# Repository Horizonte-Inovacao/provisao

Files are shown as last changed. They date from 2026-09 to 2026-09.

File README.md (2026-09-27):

<p align="center">
  <!-- [MÍDIA] Substituir pelo logo oficial (versão horizontal, Petróleo + Coral) exportado do manual de marca -->
  <em>(espaço reservado para o logo da Horizonte Inovação Assistiva)</em>
</p>

# PróVisão

**Transformando o desafio em solução.** Um boné que avisa, por vibração, o que a bengala branca não alcança.







<p align="center">
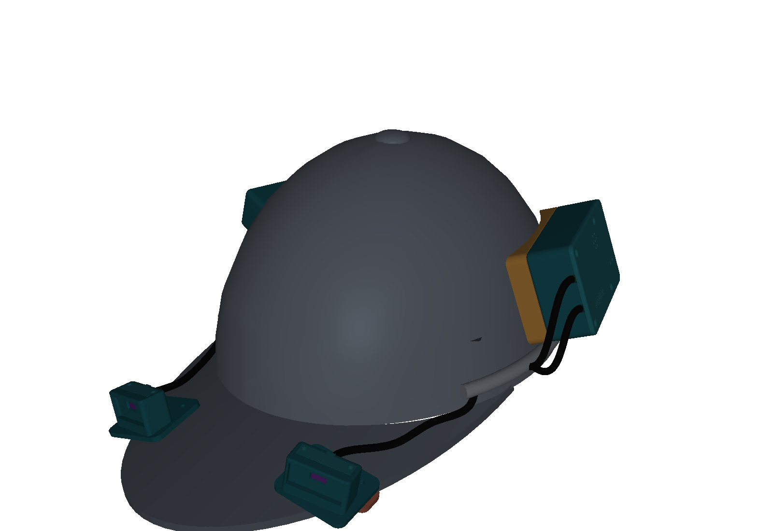
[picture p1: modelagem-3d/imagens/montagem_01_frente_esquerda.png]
Modelo 3D do boné da PróVisão com todas as peças montadas: os dois sensores na aba e os cases da eletrônica e da bateria nas laterais
  
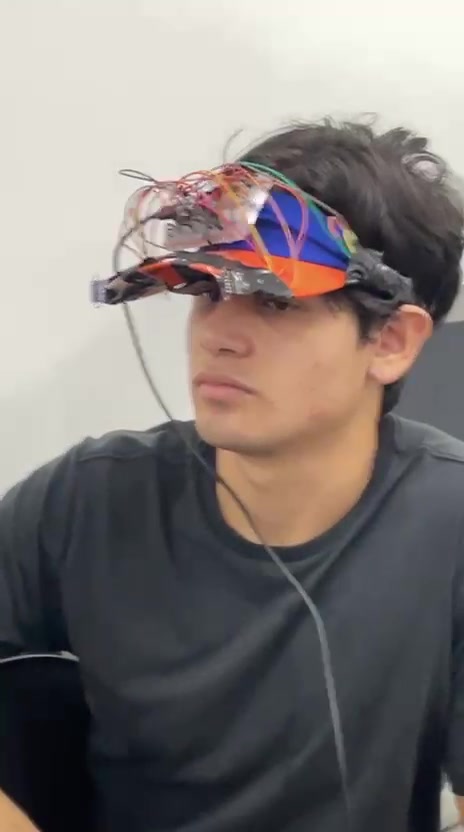
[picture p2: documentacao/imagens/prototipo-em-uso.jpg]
Integrante da equipe sentado usando o protótipo V1 da PróVisão: uma viseira azul e laranja com os dois sensores e a fiação presos na aba
  
  <br><em>À esquerda, o modelo 3D da versão 1.5, com tudo montado no boné. À direita, o protótipo V1 na viseira, em uso na apresentação da disciplina (maio de 2026). Quando o boné real ficar pronto, a foto dele entra no lugar do modelo 3D.</em>
</p>

## Por que criamos a PróVisão

A bengala branca é ótima para explorar o chão, mas não protege o que está na altura do peito e da cabeça: galhos de árvore, placas de sinalização, orelhões, lixeiras penduradas. Quem convive com deficiência visual conhece bem o risco dessas batidas.

A PróVisão é a nossa resposta. Colocamos dois sensores de distância a laser na aba de um boné comum. Quando um obstáculo alto se aproxima, o boné vibra perto da nuca, mais forte quanto mais perto ele está e do lado em que ele está. Se a distância fica perigosa, um bipe toca. Obstáculo à direita, vibração à direita: a pessoa ganha noção de direção, não só de perigo.

Na primeira versão usamos uma viseira. Trocamos pelo boné porque ele é um objeto do dia a dia: quem usa a PróVisão não precisa andar com algo que tenha cara de equipamento.

Os componentes eletrônicos custam cerca de R$ 150, enquanto soluções importadas parecidas chegam a custar dez vezes mais. Acreditamos que tecnologia assistiva precisa ser acessível também no preço.

> **Importante:** a PróVisão **complementa** a bengala branca, nunca substitui. É um protótipo experimental em fase de validação. Antes de qualquer uso, leia [documentacao/seguranca.md](documentacao/seguranca.md).

## Como funciona

```mermaid
flowchart LR
    subgraph Aba do boné
        SE["Sensor a laser esquerdo"]
        SD["Sensor a laser direito"]
    end
    MCU["Placa ESP32-C3<br/>(decide o alerta)"]
    subgraph Perto da nuca
        ME["Motor de vibração esquerdo"]
        MD["Motor de vibração direito"]
    end
    BZ["Bipe<br/>(distância perigosa)"]
    subgraph Energia
        BAT["Bateria 14500<br/>com proteção"] --> CARR["Carregador<br/>USB-C"]
        CARR --> CH["Chave<br/>liga/desliga"]
    end
    SE --> MCU
    SD --> MCU
    MCU --> ME
    MCU --> MD
    MCU --> BZ
    CH --> MCU
```

Cada sensor mede a distância pelo tempo que um feixe de luz infravermelha leva para ir até o obstáculo e voltar. Ele alcança cerca de 2 metros em ambiente fechado, com precisão de milímetros. A placa transforma essa distância em três níveis de vibração e toca o bipe abaixo de 30 cm. Explicamos cada parte, com calma, em [documentacao/como-funciona.md](documentacao/como-funciona.md).

## O que tem neste repositório

| Pasta | O que você encontra |
|---|---|
| [`firmware/`](firmware/) | O programa que roda na placa ESP32-C3 |
| [`eletronica/`](eletronica/) | Esquema de ligações e lista de materiais |
| [`modelagem-3d/`](modelagem-3d/) | Peças impressas em 3D, o boné montado e o pedido de impressão |
| [`documentacao/`](documentacao/) | Como funciona, segurança, roteiro de testes e as decisões que tomamos |
| [`fotos-e-videos/`](fotos-e-videos/) | Registro do desenvolvimento e dos testes |
| [`HISTORICO.md`](HISTORICO.md) | A linha do tempo do projeto, do diagnóstico até hoje |

Mantivemos três nomes em inglês de propósito. `README.md`, `LICENSE` e `CONTRIBUTING.md` são nomes que o GitHub reconhece e exibe em destaque. E a pasta `firmware/` guarda as subpastas `src/` e `include/`, que a ferramenta de compilação (PlatformIO) exige com esses nomes.

## Onde estamos e para onde vamos

| Versão | O que é | Situação |
|---|---|---|
| V1 | Protótipo em placa de testes, preso numa viseira. Validado em sala (nota máxima na disciplina) e apresentado à ACACE | Concluída |
| **V1.5** | Boné com placa soldada, peças impressas em 3D, bateria mais segura e motores na nuca, pronto para o teste de campo com usuários | **Em construção** |
| V2 | Placa de circuito própria, bem menor, e programa preparado para registrar dados de uso | Planejada |
| V3 | Sensores que funcionem bem sob sol direto e envio de dados por Bluetooth | Futuro |

As discussões do dia a dia ficam nas [Issues](../../issues).

## Como gravar o programa na placa

```bash
git clone https://github.com/Horizonte-Inovacao/provisao.git
cd provisao/firmware
pio run                 # compila
pio run -t upload       # grava no ESP32-C3 pelo cabo USB-C
pio device monitor      # mostra as mensagens da placa no computador
```

Antes de gravar, desligue a chave do boné. O motivo está em [documentacao/seguranca.md](documentacao/seguranca.md).

Todos os ajustes (pinos, distâncias, força da vibração) ficam em [`firmware/include/config.h`](firmware/include/config.h). Dá para calibrar o boné sem mexer na lógica do programa.

## A eletrônica em resumo

Uma placa ESP32-C3 Super Mini, dois sensores de distância a laser VL53L0X, dois motores de vibração tipo moeda, um bipe, uma bateria 14500 de 3,7 V com proteção e um carregador USB-C. O esquema completo está em [`eletronica/esquema-eletrico.md`](eletronica/esquema-eletrico.md) e tudo o que precisa ser comprado está em [`eletronica/lista-de-materiais.csv`](eletronica/lista-de-materiais.csv).

## Registro em imagens

O acervo completo, com os arquivos já reduzidos, fica em [`fotos-e-videos/`](fotos-e-videos/). Os GIFs não têm som, por isso escolhemos trechos que se explicam só com a imagem.

| Momento | Mídia |
|---|---|
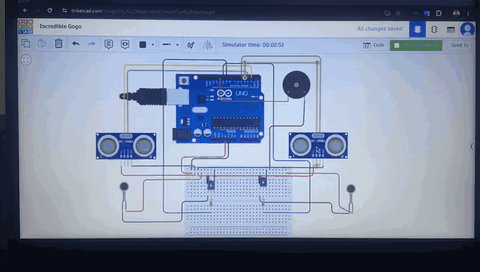
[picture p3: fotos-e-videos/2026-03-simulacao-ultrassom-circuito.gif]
GIF sem som: simulação no computador de uma placa Arduino Uno ligada a dois sensores ultrassônicos e a um bipe. Um cone azul mostra o sensor da direita detectando um obstáculo virtual
| Primeiro teste da lógica, no simulador (março de 2026) |  |
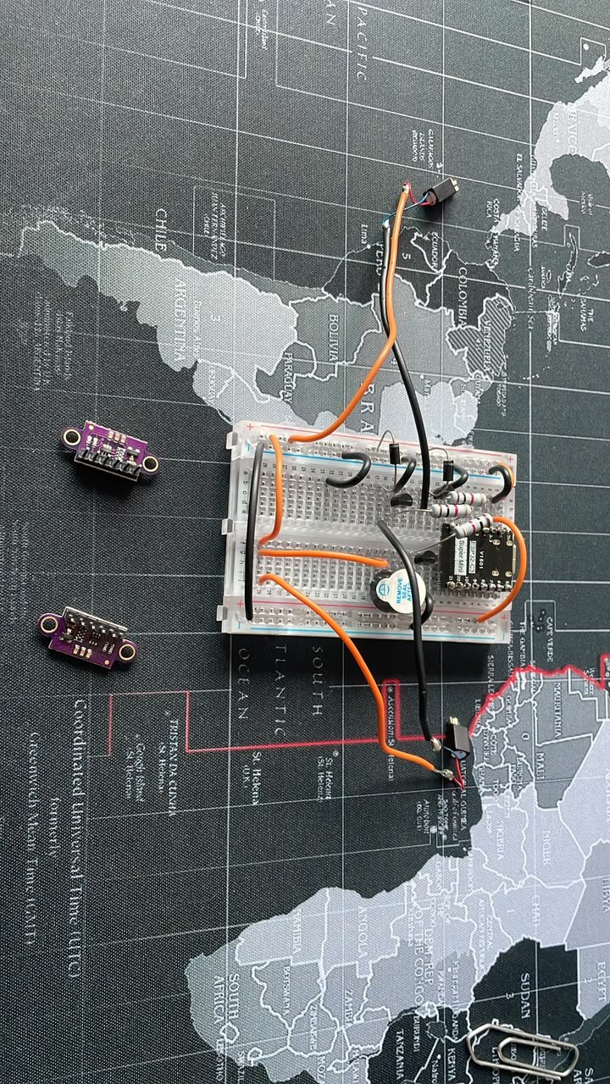
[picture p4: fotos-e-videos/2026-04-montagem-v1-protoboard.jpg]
Foto de cima da bancada: placa ESP32-C3 e fios coloridos numa placa de testes, com os dois sensores a laser roxos ao lado, sobre um mouse pad com mapa-múndi
| Bancada: protótipo V1 na placa de testes (abril de 2026) |  |
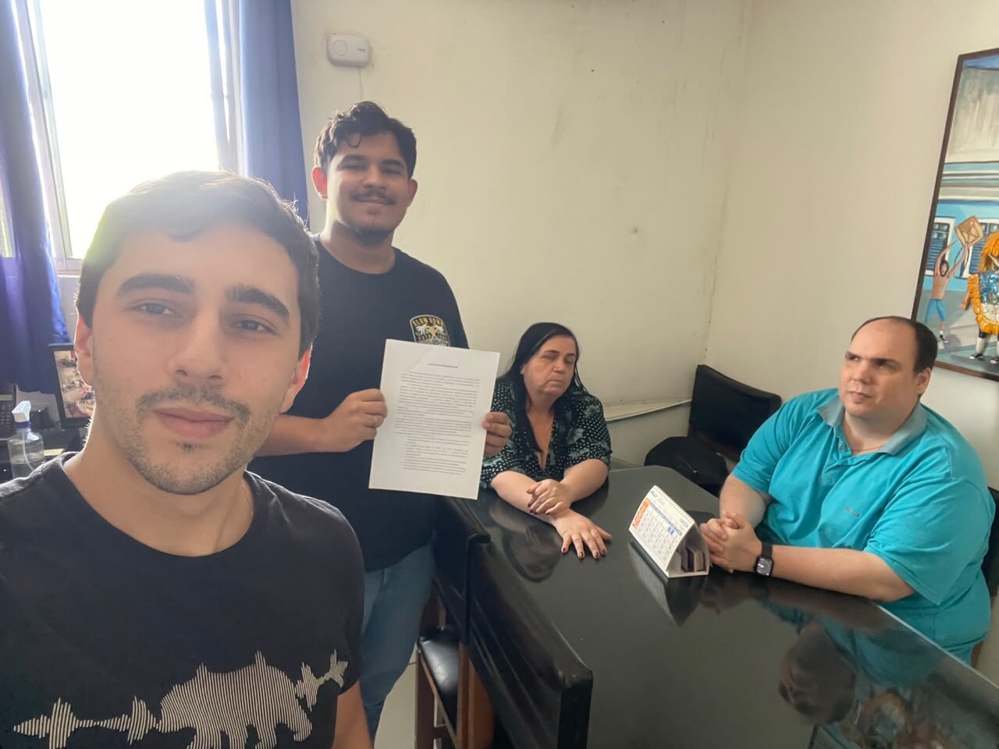
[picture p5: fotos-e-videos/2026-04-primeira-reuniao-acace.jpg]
Selfie numa sala da ACACE: dois integrantes da equipe em pé, um deles segurando um documento, e o presidente e a vice-presidente da associação sentados à mesa
| Primeira reunião com a ACACE (abril de 2026) |  |
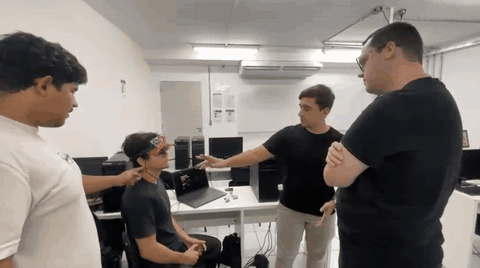
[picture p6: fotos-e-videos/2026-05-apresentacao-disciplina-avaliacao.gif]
GIF sem som: na sala de aula, um integrante sentado usa a viseira com os sensores enquanto outro explica o funcionamento e aponta para a aba. Outras duas pessoas acompanham em pé
| Apresentação em sala (maio de 2026, nota máxima) |  |
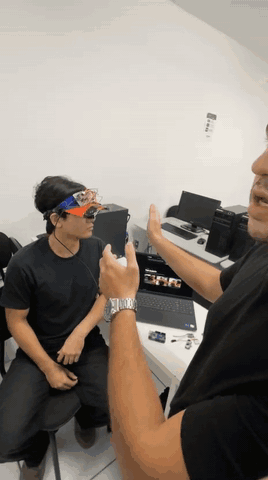
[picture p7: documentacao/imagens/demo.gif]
GIF sem som: um integrante sentado usa a viseira com os sensores enquanto outro aproxima a mão aberta dos lados da cabeça dele, simulando um obstáculo na altura da cabeça
| O protótipo V1 em uso, com a mão no papel do obstáculo (maio de 2026) |  |
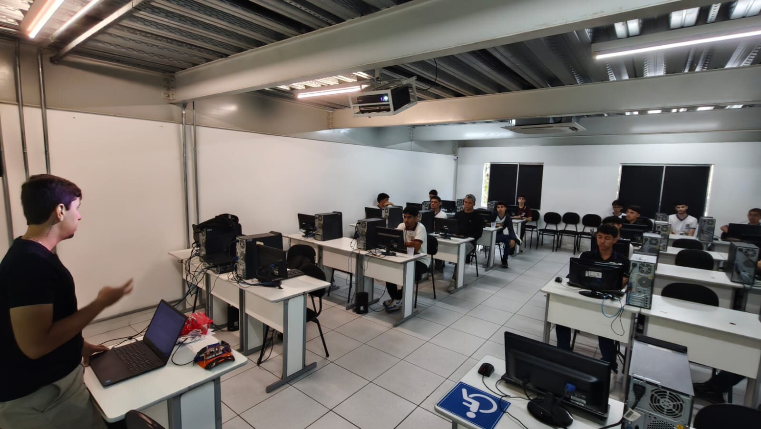
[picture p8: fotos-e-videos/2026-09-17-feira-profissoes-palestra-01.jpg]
Laboratório de informática com estudantes sentados nos computadores assistindo à palestra. À esquerda, um integrante da equipe fala em pé, ao lado do notebook e do protótipo V1 sobre a mesa
| Palestra na feira de profissões da faculdade (17 de setembro de 2026) |  |

## Como o projeto começou

A PróVisão nasceu em 2026.1 como projeto de extensão da disciplina de Programação de Microcontroladores do Centro Universitário UniFavip Wyden, em Caruaru-PE, com orientação do Prof. Rodrigo Frutuoso Lopes e em parceria com a **ACACE (Associação Caruaruense de Cegos e Amblíopes)**. Foi ouvindo os associados da ACACE que tomamos as decisões mais importantes do produto, como avisar o lado do obstáculo pela vibração. Hoje mantemos o projeto como o primeiro produto da **Horizonte Inovação Assistiva**.

## Equipe

| | |
|---|---|
| **Edson Gabriel Soares da Fonseca** | Programa da placa e liderança técnica |
| **Nadson Alex da Silva** | Eletrônica e protótipo físico |
| **João Luiz Pereira Filho** | Relação com as instituições, qualidade e testes de campo |

## Licenças

A PróVisão é aberta e recíproca: qualquer pessoa pode estudar, usar e adaptar o projeto, mas quem distribuir uma versão modificada precisa publicar as próprias melhorias sob a mesma licença e manter o nosso crédito. Contamos por que escolhemos esse caminho na [decisão 006](documentacao/decisoes/006-licencas.md).

| Parte do projeto | Licença | Texto completo |
|---|---|---|
| Programa da placa (`firmware/`) | GNU GPL 3.0 | [`firmware/LICENSE`](firmware/LICENSE) |
| Eletrônica e peças 3D (`eletronica/`, `modelagem-3d/`) | CERN-OHL-S 2.0 | [`eletronica/LICENCA-HARDWARE.md`](eletronica/LICENCA-HARDWARE.md) |
| Documentação, fotos e vídeos | CC BY-NC-SA 4.0 (sem uso comercial) | [`documentacao/LICENCA-DOCUMENTACAO.md`](documentacao/LICENCA-DOCUMENTACAO.md) |

O resumo de tudo, com as exceções, está no [`LICENSE`](LICENSE). Os nomes PróVisão e Horizonte Inovação Assistiva e o logo não fazem parte dessas licenças. As versões publicadas antes de setembro de 2026 saíram sob MIT, CERN-OHL-P 2.0 e CC BY-SA 4.0 e continuam valendo nessas condições para quem as obteve.

---

<p align="center"><sub>Horizonte Inovação Assistiva · clara, confiável e humana · Caruaru-PE</sub></p>

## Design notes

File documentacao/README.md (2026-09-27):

# Documentação

Aqui reunimos tudo o que explica a PróVisão por escrito. Se você está chegando agora, sugerimos ler nesta ordem:

1. [Como a PróVisão funciona](como-funciona.md): o caminho do sensor até a vibração, sem pressupor conhecimento de eletrônica.
2. [Segurança](seguranca.md): as regras da bateria, da gravação do programa, do conforto e da privacidade nos testes. Leitura obrigatória antes de usar o boné.
3. [Roteiro dos testes de campo](protocolo-de-testes.md): como conduzimos as sessões com os voluntários da ACACE e o que medimos.
4. [Registro das nossas decisões](decisoes/): por que escolhemos o sensor a laser, o boné, a bateria 14500, a forma de fixar as peças e o jeito de deixar tudo confortável.

A pasta [`imagens/`](imagens/) guarda as figuras usadas nestes documentos.

Os textos desta pasta estão sob a licença CC BY-NC-SA 4.0. Explicamos o que ela permite em [LICENCA-DOCUMENTACAO.md](LICENCA-DOCUMENTACAO.md).

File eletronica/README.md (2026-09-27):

# Eletrônica

Nesta pasta ficam as ligações do circuito e a lista do que precisa ser comprado.

| Arquivo | O que é |
|---|---|
| [`esquema-eletrico.md`](esquema-eletrico.md) | Todas as ligações da V1.5, pino por pino, explicadas passo a passo |
| [`lista-de-materiais.csv`](lista-de-materiais.csv) | Tudo o que precisa ser comprado para montar um boné, com quantidade, para que serve e como procurar na loja. Abre em qualquer planilha |
| [`LICENCA-HARDWARE.md`](LICENCA-HARDWARE.md) | A licença aberta e recíproca (CERN-OHL-S 2.0) da eletrônica e das peças 3D |

Combinamos uma regra: **toda mudança no circuito atualiza o esquema e a lista de materiais juntos.** Assim os dois nunca contam histórias diferentes.

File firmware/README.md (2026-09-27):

# Programa da placa (firmware)

Aqui fica o programa que roda na placa ESP32-C3 do boné. Mantivemos o nome da pasta e das subpastas em inglês porque a ferramenta que compila o programa, o PlatformIO, procura exatamente por `src/` e `include/`.

| Onde | O que tem |
|---|---|
| [`src/main.cpp`](src/main.cpp) | A lógica: lê os sensores, decide o nível de alerta, vibra os motores e toca o bipe |
| [`include/config.h`](include/config.h) | Todos os ajustes: pinos, distâncias de cada nível e força da vibração |
| [`platformio.ini`](platformio.ini) | Configuração da compilação (placa, bibliotecas, velocidade da comunicação) |
| [`legado/`](legado/) | O programa original da V1, guardado para consulta |

## Como compilar e gravar

Você precisa do [PlatformIO](https://platformio.org/) instalado (ele funciona sozinho ou dentro do VS Code).

```bash
cd firmware
pio run                 # compila
pio run -t upload       # grava na placa pelo cabo USB-C
pio device monitor      # mostra as mensagens da placa
```

**Antes de gravar, desligue a chave do boné** (ou desencaixe a bateria). A explicação está em [`documentacao/seguranca.md`](../documentacao/seguranca.md).

## Como calibrar

Tudo o que é ajuste fica em `include/config.h`. Por exemplo, para o boné começar a vibrar mais longe, aumente `DIST_NIVEL_1`. Para vibrar mais forte, aumente os valores de `DUTY_NIVEL`, lembrando que os motores são de 1 a 3 V e por isso existe um teto. Combinamos que a lógica em `main.cpp` não recebe números soltos: se é ajuste, vai para o `config.h`.

## Verificação automática

A cada alteração nesta pasta, o GitHub compila o programa sozinho (arquivo [`.github/workflows/firmware.yml`](../.github/workflows/firmware.yml)). Se a compilação falhar, a alteração aparece marcada com erro.

## Licença

O programa da V1.5 está sob a GNU GPL 3.0, com o texto completo em [`LICENSE`](LICENSE). A V1, guardada em `legado/`, continua sob a licença MIT com que foi publicada ([`legado/LICENSE-MIT`](legado/LICENSE-MIT)).

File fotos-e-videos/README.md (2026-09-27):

# Fotos e vídeos do projeto

Aqui ficam as fotos e os vídeos que contam a história da PróVisão. Antes de colocar qualquer arquivo, combinamos duas regras:

1. **Pessoas que dá para reconhecer só entram com autorização de imagem assinada.** Isso vale para participantes da ACACE, colegas e professores. Sem autorização, a foto não é publicada.
2. **Reduza o arquivo antes de subir.** Foto com até 1 MB, vídeo curto ou convertido em GIF. Os arquivos originais, pesados, ficam na pasta `fotos-e-videos/originais/`, que o Git ignora de propósito.

## Como nomear os arquivos

`ANO-MES-DIA-descricao-curta.extensao`, por exemplo `2026-05-20-apresentacao-em-sala.jpg`. A data é a do evento, não a do envio pelo WhatsApp. Quando não sabemos o dia exato, usamos `ANO-MES-descricao-curta.extensao`, por exemplo `2026-05-apresentacao-disciplina-demo-obstaculo.gif`.

Tudo em minúsculas, sem acentos e com hífen entre as palavras.

## O que já temos para adicionar

- [x] Fotos da apresentação final em sala (2026.1, nota máxima). Temos vídeos, que viraram GIFs e um quadro parado
- [x] Vídeos de colegas usando o dispositivo em sala, convertidos em GIF
- [x] Fotos do protótipo V1 na placa de testes (bancada)
- [x] Registros da atividade com a ACACE: foto da primeira reunião, com autorização de imagem
- [x] Simulação e primeiro teste do programa, convertidos em GIF
- [x] Feira de profissões da faculdade (17 de setembro de 2026)
- [ ] Logo e aplicações do manual de marca (exportar do PDF). O `logo-horizonte.png` desta pasta tem só o símbolo
- [ ] Fotos da montagem da V1.5 no boné

## O que já está no acervo

| Arquivo | Momento | O que mostra |
|---|---|---|
| [`2026-03-simulacao-ultrassom-circuito.gif`](2026-03-simulacao-ultrassom-circuito.gif) | Simulação (março de 2026) | O circuito inteiro no simulador, com Arduino Uno, dois sensores ultrassônicos e bipe, e o sensor da direita detectando um obstáculo |
| [`2026-03-simulacao-ultrassom-detalhe.gif`](2026-03-simulacao-ultrassom-detalhe.gif) | Simulação (março de 2026) | Detalhe do sensor da direita, com a distância medida escrita na tela |
| [`2026-04-primeiro-teste-monitor-serial.gif`](2026-04-primeiro-teste-monitor-serial.gif) | Primeiro teste na placa (abril de 2026) | O monitor serial com a distância de cada sensor e o estado dos motores e do bipe |
| [`2026-04-montagem-v1-bancada.jpg`](2026-04-montagem-v1-bancada.jpg) | Montagem da V1 (abril de 2026) | A bancada com ferro de solda, ferramentas e a placa de testes |
| [`2026-04-montagem-v1-protoboard.jpg`](2026-04-montagem-v1-protoboard.jpg) | Montagem da V1 (abril de 2026) | A ESP32-C3 e os fios na placa de testes, com os dois sensores a laser |
| [`2026-04-montagem-v1-esp32-e-sensores.jpg`](2026-04-montagem-v1-esp32-e-sensores.jpg) | Montagem da V1 (abril de 2026) | A ESP32-C3 na mini placa de testes vermelha, com um sensor a laser |
| [`2026-04-montagem-v1-fiacao.jpg`](2026-04-montagem-v1-fiacao.jpg) | Montagem da V1 (abril de 2026) | A fiação saindo da placa de testes para os sensores |
| [`2026-04-primeira-reuniao-acace.jpg`](2026-04-primeira-reuniao-acace.jpg) | Primeira reunião com a ACACE (abril de 2026) | Dois integrantes da equipe com o presidente e a vice-presidente da ACACE |
| [`2026-05-apresentacao-disciplina-avaliacao.gif`](2026-05-apresentacao-disciplina-avaliacao.gif) | Apresentação na disciplina (maio de 2026) | A explicação do protótipo durante a avaliação |
| [`2026-05-apresentacao-disciplina-demo-obstaculo.gif`](2026-05-apresentacao-disciplina-demo-obstaculo.gif) | Apresentação na disciplina (maio de 2026) | A mão simulando um obstáculo dos lados da cabeça de quem usa a viseira |
| [`2026-05-apresentacao-disciplina-viseira-detalhe.gif`](2026-05-apresentacao-disciplina-viseira-detalhe.gif) | Apresentação na disciplina (maio de 2026) | Close da viseira V1 na cabeça, com sensores, placa e fiação |
| [`2026-05-apresentacao-disciplina-viseira-em-uso.jpg`](2026-05-apresentacao-disciplina-viseira-em-uso.jpg) | Apresentação na disciplina (maio de 2026) | Quadro parado do vídeo: a viseira V1 em uso |
| [`2026-09-17-feira-profissoes-palestra-01.jpg`](2026-09-17-feira-profissoes-palestra-01.jpg) | Feira de profissões (17/09/2026) | A palestra, com o público no laboratório |
| [`2026-09-17-feira-profissoes-palestra-02.jpg`](2026-09-17-feira-profissoes-palestra-02.jpg) | Feira de profissões (17/09/2026) | A palestra, de outro momento |
| [`2026-09-17-feira-profissoes-palestra-03.jpg`](2026-09-17-feira-profissoes-palestra-03.jpg) | Feira de profissões (17/09/2026) | A palestra, de outro momento |
| [`2026-09-17-feira-profissoes-equipe-e-visitantes.jpg`](2026-09-17-feira-profissoes-equipe-e-visitantes.jpg) | Feira de profissões (17/09/2026) | A equipe com estudantes visitantes em frente à projeção do site |
| [`2026-09-17-feira-profissoes-sala.gif`](2026-09-17-feira-profissoes-sala.gif) | Feira de profissões (17/09/2026) | Passeio rápido pela sala, do público ao protótipo e à projeção |

Os originais completos, sem alteração, ficam em `originais/`, separados por evento. Essa pasta não vai para o GitHub.

## Onde cada mídia aparece

| Mídia | Aparece em |
|---|---|
| Foto principal do protótipo em uso | `README.md` (topo). Copie também para `documentacao/imagens/prototipo-em-uso.jpg` |
| GIF do boné funcionando | `README.md`, na seção "Registro em imagens" |
| Fotos de bancada e do percurso | `HISTORICO.md` e `documentacao/protocolo-de-testes.md` |
| Logo | `README.md` (topo) |

Depois de adicionar um arquivo, procure pelas marcações `[MÍDIA]` no repositório (`grep -r "MÍDIA" .`). Elas mostram todos os lugares que estão esperando uma imagem.

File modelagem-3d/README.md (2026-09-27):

# Modelagem 3D

Aqui estão todas as peças impressas em 3D da PróVisão V1.5 e o boné montado com tudo no lugar. Desenhamos as peças em código (Python, com a biblioteca CadQuery), e não à mão num programa de desenho. Optamos por esse caminho porque ainda vamos medir os componentes reais com paquímetro: quando uma medida mudar, basta trocar um número e gerar tudo de novo. O porquê completo está na [decisão 004](../documentacao/decisoes/004-pecas-3d-e-fixacao-no-bone.md).

Boné montado

## Os tipos de arquivo desta pasta

| Pasta | Tipo | Para que serve |
|---|---|---|
| [`arquivos-stl/`](arquivos-stl/) | STL | A "malha" da peça, que o programa da impressora (o fatiador) lê. Já está na posição certa de imprimir |
| [`arquivos-step/`](arquivos-step/) | STEP | A peça com as medidas exatas, para abrir no FreeCAD ou no Fusion e medir ou conferir |
| [`bone-montado/`](bone-montado/) | GLB | O boné inteiro montado, para girar e ver no navegador (por exemplo em [3dviewer.net](https://3dviewer.net)) |
| [`pedido-de-impressao/`](pedido-de-impressao/) | PDF e 3MF | O pacote pronto para mandar a um serviço de impressão. O 3MF é um arquivo que junta várias peças numa mesa só |
| [`imagens/`](imagens/) | PNG | As imagens desta página, geradas automaticamente |
| [`codigo/`](codigo/) | Python | O código que desenha todas as peças |

## Onde cada peça fica no boné

```
                  aba (frente)
        S1 esq  ┌───────────────┐  S1 dir        suportes dos sensores, 5 mm atrás da borda da aba
                │               │
   case A  ▐████│    copa       │████▌  case B    laterais opostas, para equilibrar o peso
  (esquerda)    │               │   (direita)
                └──M1───────M1──┘                motores dentro da faixa interna, perto da nuca
                     nuca
```

| Conjunto | Lado | Como fica virado |
|---|---|---|
| Case A (eletrônica) | lateral esquerda | entradas dos cabos dos sensores para a frente, USB-C de carga para baixo, chave virada para a nuca |
| Case B (bateria) | lateral direita | tampa com o cabo virada para a nuca, furinhos de ventilação para fora da cabeça |
| Suportes dos sensores | aba, 50 mm para cada lado do centro | sensor olhando para a frente, 10 graus aberto para fora |
| Berços dos motores | faixa interna, perto da nuca | bolsinho do motor virado para a cabeça |

O case A foi desenhado para o lado esquerdo. Se ele for montado no direito, o USB-C fica virado para cima, e por isso a troca de lado precisa ser feita no código, não só girando a peça.

## As peças

| Arquivo | Quantidade | Material | Como imprimir |
|---|---|---|---|
| `A1_case_eletronica_corpo` | 1 | PETG | como está, sem suporte |
| `A2_case_eletronica_tampa` | 1 | PETG | já sai virada, com a face de fora na mesa |
| `A3_case_eletronica_base_curva` | 1 | PETG | face plana na mesa, 15% de preenchimento |
| `A4_case_eletronica_placa_interna` | 1 | PETG | plana. Ela se curva sozinha ao ser parafusada |
| `B1_case_bateria_corpo` | 1 | PETG | **em pé**, com a ponta fechada na mesa, sem suporte e com borda de adesão (brim) de 5 mm |
| `B2_case_bateria_tampa` | 1 | PETG | face de fora na mesa |
| `B3_case_bateria_placa_interna` | 1 | PETG | plana |
| `S1_suporte_sensor_esquerdo_XXgraus` | 1 de cada inclinação | PETG | base na mesa |
| `S1_suporte_sensor_direito_XXgraus` | 1 de cada inclinação | PETG | base na mesa |
| `S2_suporte_sensor_tampa` | 2 | PETG | plana |
| `S3_suporte_sensor_placa_sob_aba` | 2 | PETG | com os encaixes das porcas para cima |
| `M1_berco_motor` | 2 | **TPU 95A** | aba na mesa |

Escolhemos o **PETG** para o corpo das peças porque o PLA, o plástico mais comum, amolece no calor de um dia de sol, e o boné vai na cabeça, ao ar livre. O **TPU** é um plástico flexível, parecido com borracha: usamos só no berço do motor, que encosta na nuca.

**Configuração de impressão:** camada de 0,2 mm, **4 paredes** (é o que segura os parafusos e aguenta pancada), 25% de preenchimento em padrão giroide e nenhum suporte. Todas as peças foram desenhadas para imprimir sem suporte.

## Parafusos

Padronizamos **um único tamanho de parafuso, o M2** (2 mm de diâmetro), no projeto inteiro. Os furos têm 1,7 mm, e o parafuso abre a própria rosca no plástico.

| Onde | Parafuso | Quantidade |
|---|---|---|
| Tampa e placa do case A (o parafuso atravessa as duas) | M2 x 20, cabeça panela | 4 |
| Case A na base curva (por dentro do piso) | M2 x 6, cabeça chata | 4 |
| Placa interna A na base curva (por dentro do boné) | M2 x 8, cabeça chata | 4 |
| Tampa do case B | M2 x 12, cabeça panela | 4 |
| Placa interna B no corpo do case B | M2 x 8, cabeça chata | 4 |
| Suporte do sensor na aba | M2 x 8, cabeça panela, com porca M2 | 4 + 4 porcas |
| Tampinha do suporte do sensor | M2 x 6, cabeça panela | 4 |

A lista completa do que comprar, com fios e metragens, está em [`eletronica/lista-de-materiais.csv`](../eletronica/lista-de-materiais.csv).

## Montagem passo a passo

### Case A (eletrônica)

1. Fure o tecido do boné usando a placa interna como molde (4 furos de 2,5 mm) e passe cola de tecido em volta dos furos para não desfiar.
2. Coloque a placa interna por dentro e a base curva por fora. Aperte 4 parafusos M2 x 8 de cabeça chata, entrando por dentro do boné.
3. Cole a almofada de EVA de 3 mm na placa interna, do lado da cabeça, cobrindo as cabeças dos parafusos. Chanfre a borda da espuma com um estilete. A parte de baixo da placa entra por trás da faixa interna do boné.
4. Coloque o corpo do case sobre a base curva e aperte os 4 parafusos M2 x 6 por dentro do piso. Faça isso **antes** de colocar a eletrônica, porque dois desses parafusos ficam embaixo do carregador e da chave.
5. Deslize o carregador nos trilhos, com o USB-C encaixado no recorte da parede. Uma gota de cola quente trava o módulo.
6. Encaixe a chave no recorte da parede de trás, **com o lado "ligado" para cima**. O pontinho em relevo ao lado da chave marca esse lado, para a pessoa achar pelo tato.
7. Passe os cabos pelos entalhes das paredes. Dentro do case, aperte uma abraçadeira no cabo logo depois da parede: ela funciona como trava, e um puxão no cabo não chega na solda.
8. Apoie a placa ilhada nos quatro apoios do fundo e coloque a tampa por cima. Os 4 parafusos M2 x 20 atravessam as colunas da tampa e a placa e prendem as duas de uma vez.
9. Encaixe um pedaço de filamento transparente em cada um dos dois tubinhos da tampa, rente à face de fora. Eles levam a luz dos LEDs do carregador para fora do case.

**Como organizar a placa ilhada:** corte a placa em 5 x 4 cm. Deixe livre um círculo de 7 mm em volta de cada furo de canto, onde descem as colunas da tampa. Mantenha o bipe na posição de `BUZZER_POS` (é embaixo dos furos de som da tampa). Coloque os conectores dos sensores na borda da frente e os dos motores e da bateria na borda de trás. Fure os cantos da placa com 2,2 mm, a 2,5 mm de cada borda.

### Case B (bateria)

1. Solde o fusível rearmável no fio positivo e cubra com termo-retrátil.
2. Enrole a bateria em EVA de 1 mm, sem apertar, e coloque um calço de EVA em cada ponta.
3. Entre com o **polo positivo primeiro** (o "+" em baixo relevo na lateral mostra o lado). O fio do polo positivo volta por um canal na lateral do furo.
4. Acomode o fusível e a emenda dentro da tampa e passe o cabo pelo furo da ponta, com uma abraçadeira de trava por dentro.
5. Feche a tampa com 4 parafusos M2 x 12.
6. Prenda no boné pela placa interna (4 parafusos M2 x 8 por dentro) e cole a almofada de EVA, como no case A.

Os furinhos de ventilação ficam em cima do polo positivo, onde a bateria alivia pressão se um dia precisar. Eles apontam para fora da cabeça: não tampe com adesivo nem tecido.

### Suportes dos sensores

1. Solde os fios direto nos furos do sensor, **sem barra de pinos** (ela não cabe e faria alavanca). Cubra cada solda com termo-retrátil.
2. Desça o sensor por cima no encaixe, com o chip virado para a frente. Um pedaço de EVA de 1 mm atrás da plaquinha tira a folga e amortece batidas.
3. Passe o cabo pelo entalhe de trás. A lingueta da tampinha fecha o entalhe por cima.
4. Feche a tampinha com 2 parafusos M2 x 6.
5. Cole a base na aba, 5 mm atrás da borda, com fita dupla face de espuma. Fure a aba (2,5 mm), coloque a plaquinha de baixo com as porcas nos encaixes e aperte 2 parafusos M2 x 8.

**Como protegemos o sensor:** a face do chip fica 4 mm para dentro, atrás de uma moldura arredondada, e a própria aba avança 5 mm à frente do suporte. Uma batida de frente pega na aba e na moldura antes de chegar no sensor. A janela abre em funil, para não atrapalhar o campo de visão de 25 graus do sensor. **Não coloque acrílico nem vidro na janela:** o sensor perde alcance com qualquer cobertura.

**Qual inclinação usar:** a aba aponta para baixo quando o boné está na cabeça, e o ângulo muda de pessoa para pessoa. Imprima as três versões (0, 10 e 20 graus) e escolha no primeiro teste a que deixa o sensor olhando reto para a frente, usando um obstáculo na altura da testa.

### Berços dos motores e conforto

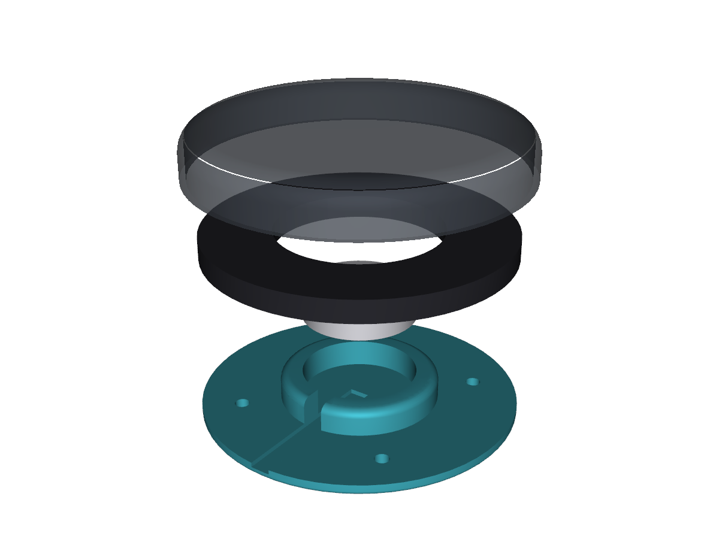
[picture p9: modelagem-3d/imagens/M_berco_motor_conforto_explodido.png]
Berço do motor, anel de EVA e bolsinho de tecido


1. Encaixe o motor no berço de TPU. O encaixe é por pressão e o motor fica 0,3 mm para fora.
2. Corte um anel de EVA de 2 mm (27 mm por fora, 14,6 mm por dentro) e encaixe em volta do motor, sobre a aba do berço.
3. Costure um bolsinho de tecido macio na faixa interna, perto da nuca, e coloque o berço dentro, com o motor virado para a cabeça. Dá para tirar o berço e lavar o boné.

A regra que seguimos para o conforto é simples: **o plástico dá a estrutura e uma camada macia faz o contato com a pele.** Contamos o raciocínio na [decisão 005](../documentacao/decisoes/005-conforto-no-contato-com-a-cabeca.md).

## O que medir antes da impressão final

Os valores marcados com `[MEDIR]` em [`codigo/pecas/medidas.py`](codigo/pecas/medidas.py) são medidas típicas de mercado. Confira com o paquímetro nos componentes que vocês têm:

| Medida | Onde medir | O que dá errado se não conferir |
|---|---|---|
| `R_COPA` | curva da lateral do boné, perto da nuca (com um molde de papelão ou uma régua flexível) | a base curva balança no boné |
| `ABA_ESPESSURA` | espessura da aba | comprimento do parafuso do sensor |
| `GY_X`, `GY_Z`, `CHIP_OFF_Y`, `CHIP_OFF_Z` | plaquinha do sensor | janela desalinhada com o chip |
| `TP_X`, `TP_Y`, `TP_LEDS`, `USB_ALTURA_CENTRO` | carregador USB-C | USB fora do recorte ou tubinho de luz fora do LED |
| `CEL_D`, `CEL_L` | bateria 14500 com as lâminas de solda | folga da bateria no tubo |
| `MOTOR_D`, `MOTOR_H` | motor de vibração | aperto do motor no berço |

Nossa sugestão: imprimir primeiro o lote de teste de encaixe (está no [pedido de impressão](pedido-de-impressao/)), conferir tudo e só então imprimir o kit completo.

## O boné montado

A montagem junta todas as peças num boné de referência, desenhado em [`codigo/pecas/bone.py`](codigo/pecas/bone.py):

- copa de 200 x 160 x 105 mm (cerca de 57 cm de circunferência);
- aba curva de 75 mm, inclinada 12 graus para baixo;
- faixa interna (carneira) de 30 mm e abertura de regulagem na nuca;
- canaleta costurada por fora, que sai da frente esquerda, contorna a nuca passando por cima da regulagem e volta pela frente direita.

O código assenta cada peça sozinho: a base curva de cada case anda até encostar no tecido sem atravessar, e a placa interna faz o mesmo pelo lado de dentro. As posições ficam em `medidas.py`, no bloco `POS_*`.

**Caminho dos cabos:** cada sensor sai pela traseira do suporte, corre por cima da aba e entra na canaleta pela frente. Os dois cabos de sensor entram no case A pela parede da frente, e os cabos dos motores e da bateria saem pela parede de trás. O cabo da bateria sai da tampa do case B e contorna a nuca pela canaleta até o case A. Os fios dos motores saem da canaleta, atravessam o tecido e chegam aos berços.

O boné de referência é genérico. As peças só vão assentar como no modelo depois de medir o boné real e ajustar `R_COPA` e as medidas da copa (`BONE_A`, `BONE_B` e `BONE_C`). Na posição atual, o case A fica entre 26 e 31 mm saltado da copa. É a placa de circuito própria da V2 que vai diminuir essa altura.

| | |
|---|---|
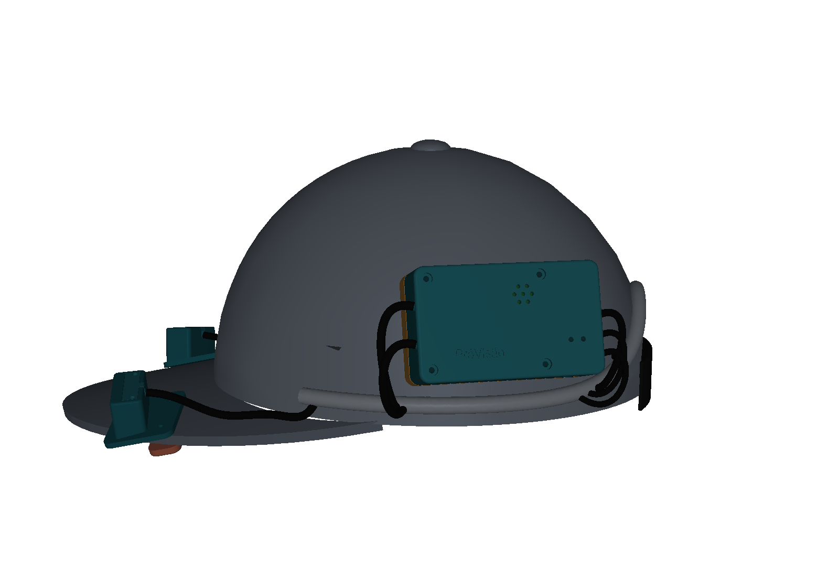
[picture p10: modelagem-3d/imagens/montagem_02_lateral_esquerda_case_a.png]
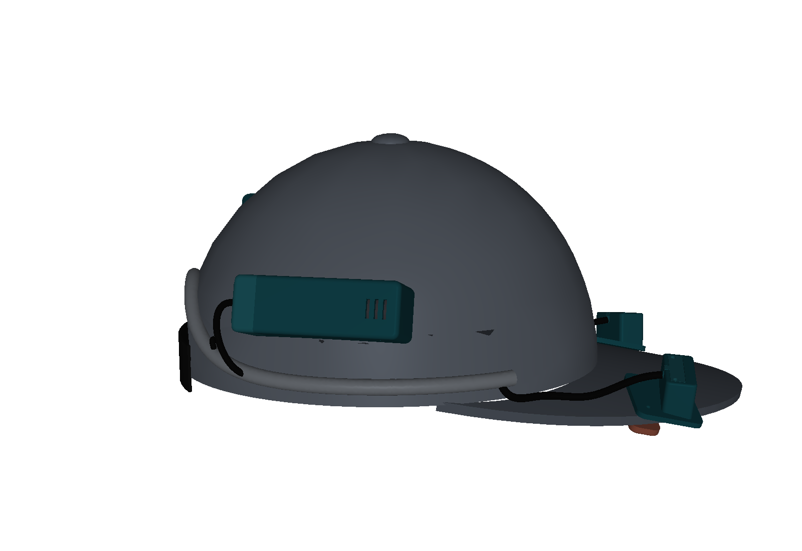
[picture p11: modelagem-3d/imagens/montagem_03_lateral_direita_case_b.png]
|  |  |
| Lateral esquerda: case A e a canaleta | Lateral direita: case B |
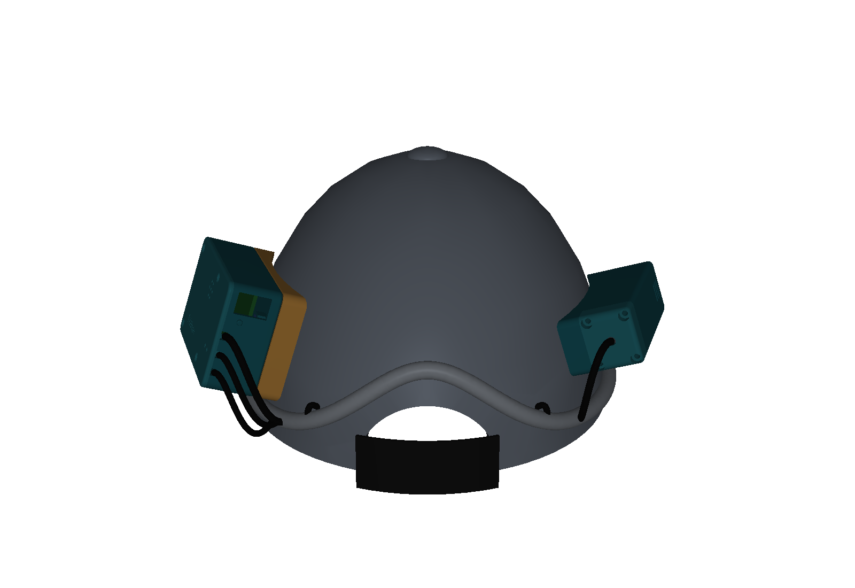
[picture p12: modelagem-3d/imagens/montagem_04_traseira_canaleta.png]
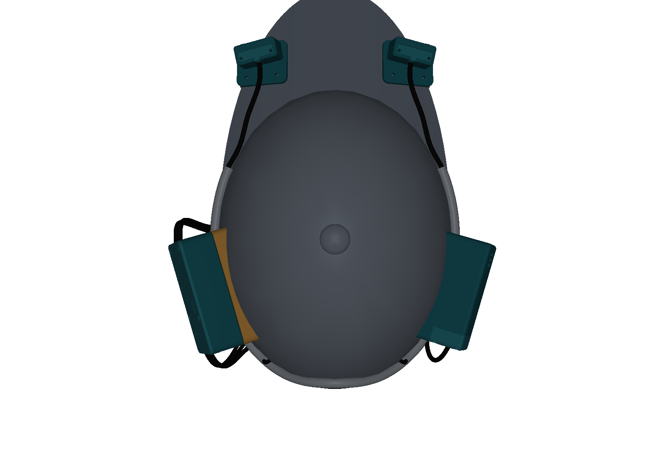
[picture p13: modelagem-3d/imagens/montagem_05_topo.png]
|  |  |
| Nuca: a canaleta passa por cima da regulagem | Vista de cima |
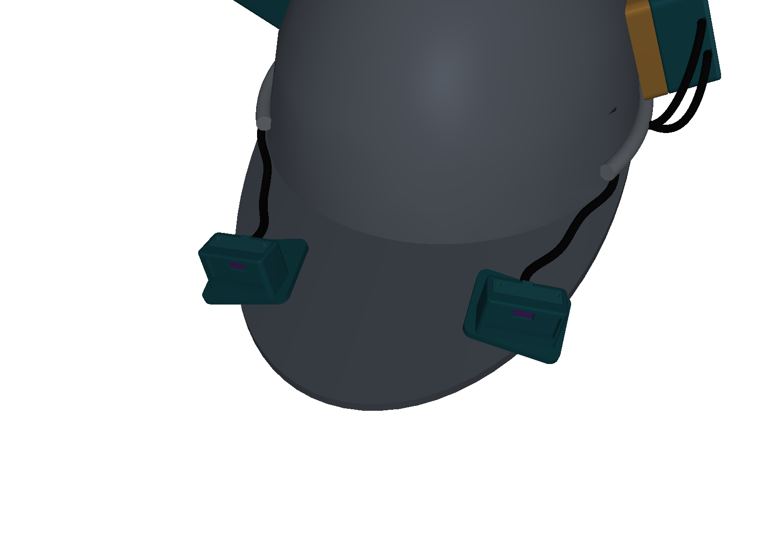
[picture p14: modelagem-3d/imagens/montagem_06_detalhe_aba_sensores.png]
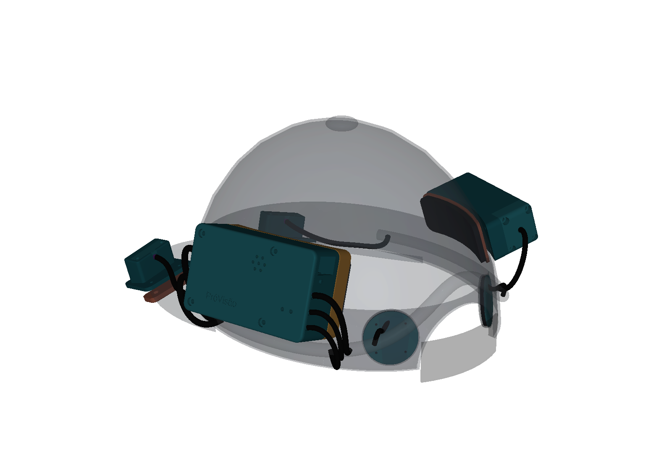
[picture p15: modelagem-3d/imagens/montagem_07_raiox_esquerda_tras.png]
|  |  |
| Suportes dos sensores na aba | Vista transparente: placas internas, almofadas, berços e componentes |

## Como gerar tudo de novo

Você precisa do Python 3 e da biblioteca CadQuery (`pip install cadquery`). Depois:

```bash
cd modelagem-3d/codigo
python3 verificar_encaixes.py   # confere se alguma peça atravessa outra ou um componente
python3 gerar_pecas.py          # gera os arquivos STEP e STL
python3 gerar_imagens.py        # gera as imagens das peças
python3 montar_bone.py          # gera o boné montado (STEP, GLB e imagens)
python3 montar_bone.py --verificar   # confere se alguma peça atravessa o boné
python3 gerar_pedido_impressao.py    # refaz o pacote do pedido de impressão
```

O `verificar_encaixes.py` monta cada conjunto com versões simplificadas dos componentes (placa, carregador, USB-C, chave, bipe, bateria e sensor) e avisa se qualquer par se cruzar. O `gerar_pecas.py` também avisa se alguma malha sair aberta, porque serviços de impressão recusam esse tipo de arquivo.

## Como a pasta está organizada

```
modelagem-3d/
├── codigo/
│   ├── pecas/
│   │   ├── medidas.py            todas as medidas, num lugar só
│   │   ├── auxiliares.py         base curva, placa interna, furos e outras funções de apoio
│   │   ├── case_eletronica.py    case A
│   │   ├── case_bateria.py       case B
│   │   ├── suporte_sensor.py     suportes da aba
│   │   ├── berco_motor.py        berço, anel de EVA e bolsinho
│   │   ├── bone.py               o boné de referência
│   │   └── montagem.py           posições, assentamento e cabos do boné montado
│   ├── gerar_pecas.py  gerar_imagens.py  verificar_encaixes.py
│   └── montar_bone.py  gerar_pedido_impressao.py
├── arquivos-step/                peças e boné montado, com as medidas exatas
├── arquivos-stl/                 peças prontas para o fatiador
├── bone-montado/                 boné montado para ver no navegador
├── pedido-de-impressao/          pacote para o serviço de impressão
└── imagens/                      imagens geradas
```

## Imagens das peças

| | |
|---|---|
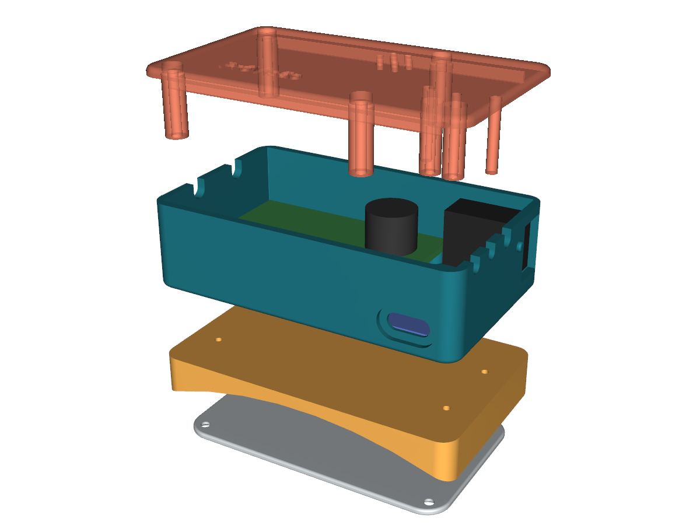
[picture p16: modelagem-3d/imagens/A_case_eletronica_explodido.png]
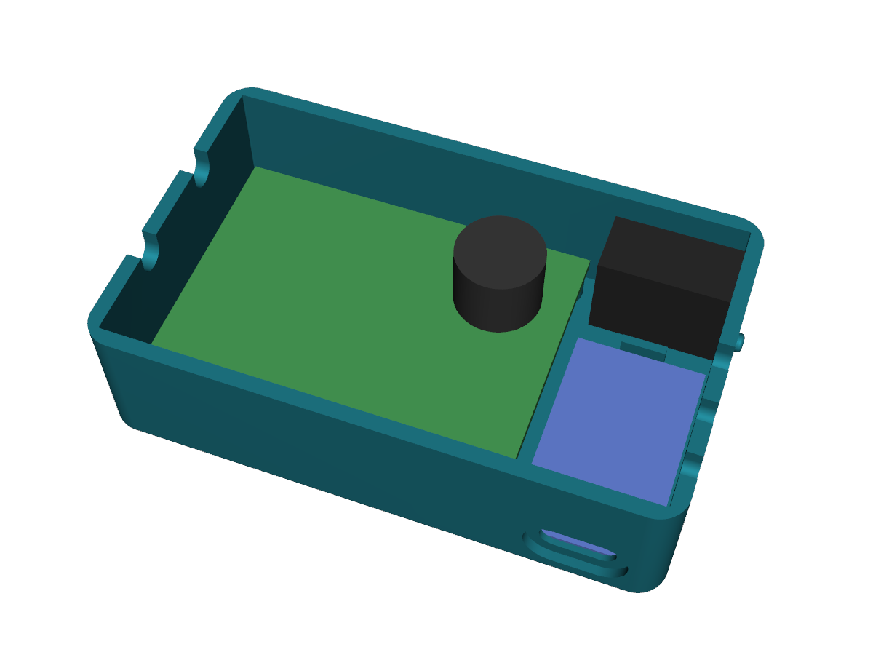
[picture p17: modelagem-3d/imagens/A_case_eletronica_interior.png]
|  |  |
| Case A desmontado | Case A por dentro |
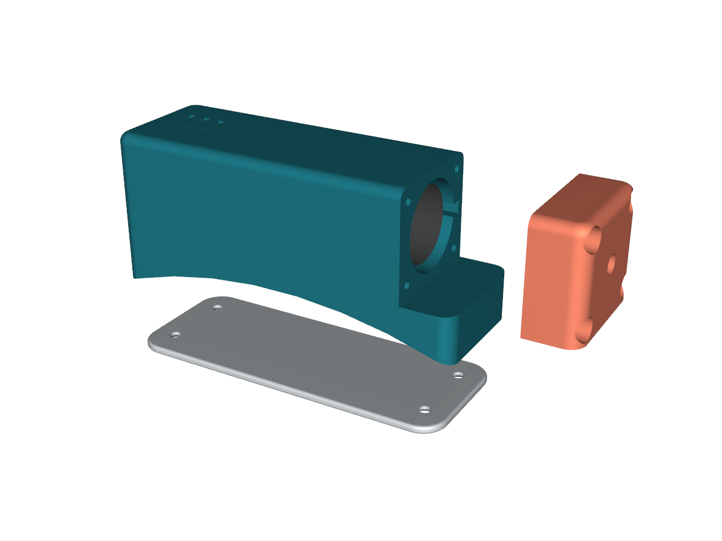
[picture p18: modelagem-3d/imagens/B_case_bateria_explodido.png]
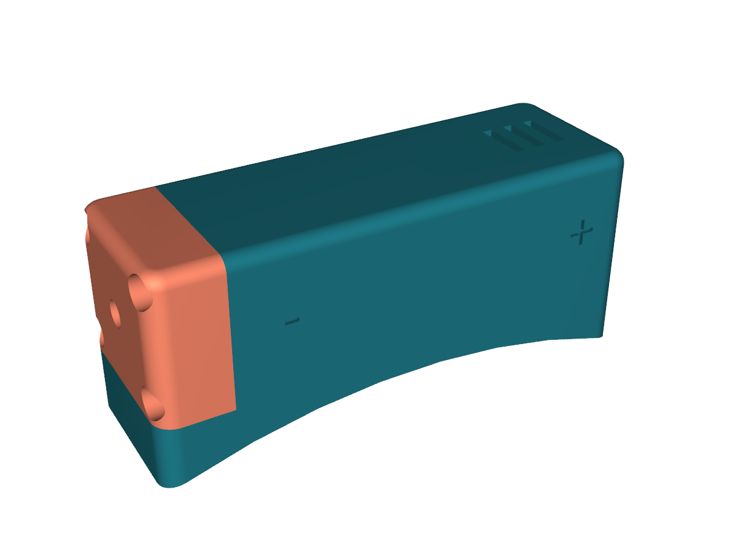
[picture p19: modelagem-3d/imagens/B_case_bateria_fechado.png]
|  |  |
| Case B desmontado | Case B fechado |
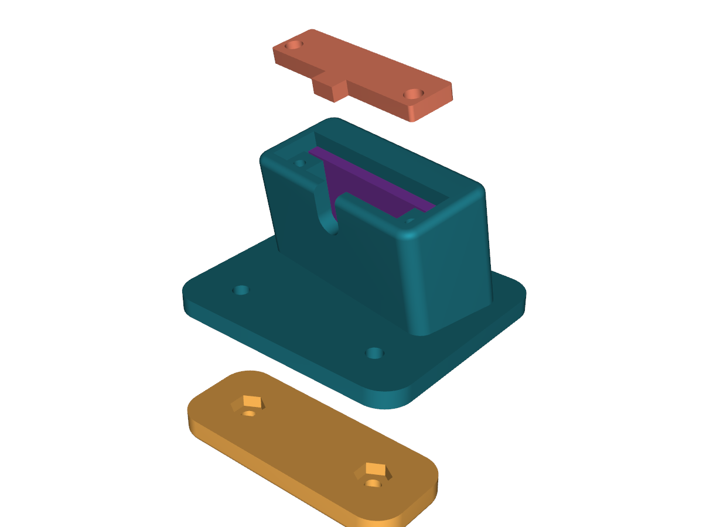
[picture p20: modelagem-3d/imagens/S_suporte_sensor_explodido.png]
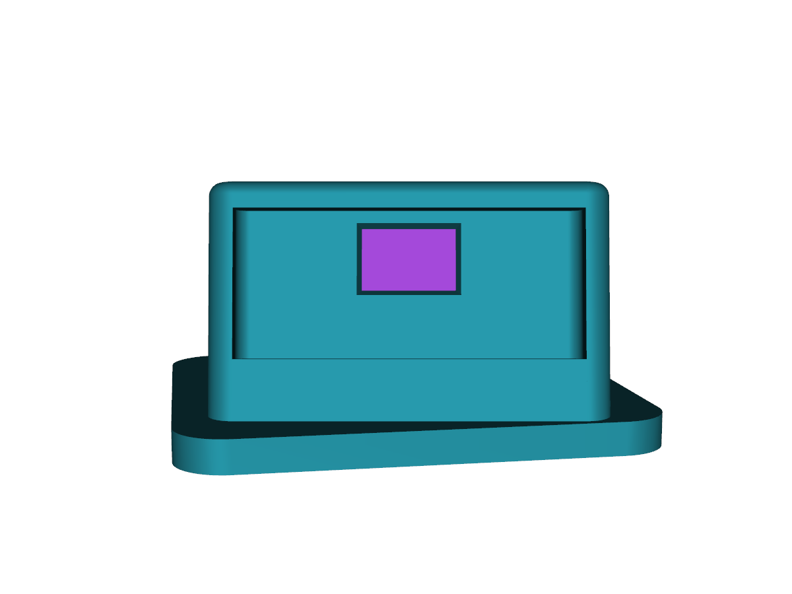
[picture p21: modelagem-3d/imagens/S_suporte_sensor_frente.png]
|  |  |
| Suporte do sensor desmontado | Suporte do sensor visto de frente |
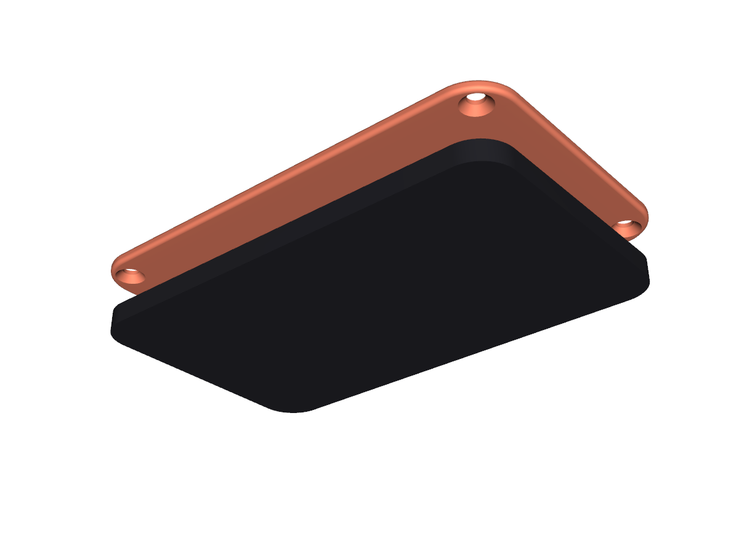
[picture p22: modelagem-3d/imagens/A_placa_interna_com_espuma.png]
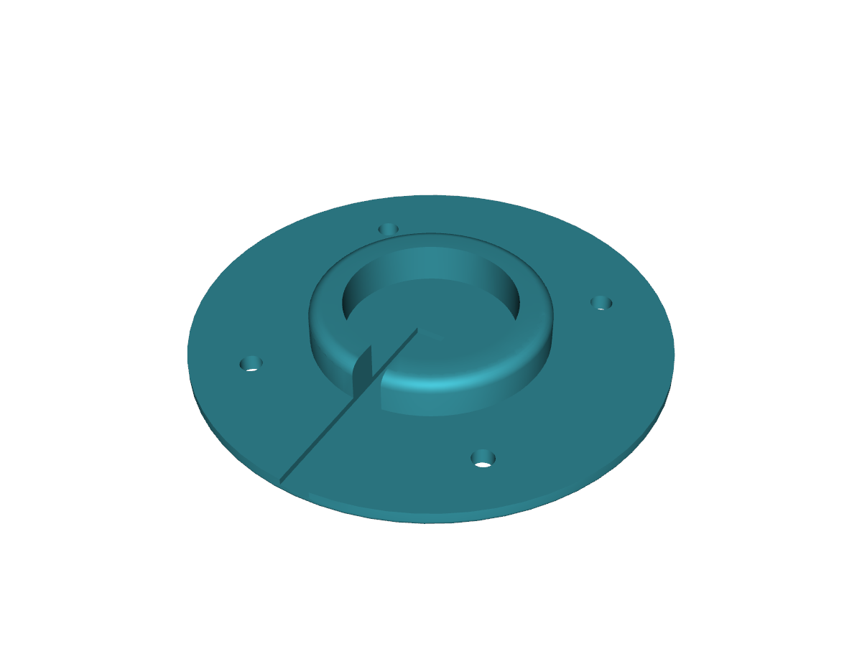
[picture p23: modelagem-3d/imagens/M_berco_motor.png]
|  |  |
| Placa interna e almofada de EVA | Berço do motor em TPU |

## Licença

As peças, o código que as desenha e as imagens desta pasta estão sob a CERN-OHL-S 2.0, a mesma licença da eletrônica. O texto completo está em [`eletronica/LICENCA-HARDWARE.md`](../eletronica/LICENCA-HARDWARE.md).

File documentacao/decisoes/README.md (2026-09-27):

# Registro das nossas decisões

Toda vez que tomamos uma decisão que muda o rumo do projeto, escrevemos um registro curto aqui. Cada registro conta o problema que tínhamos, o que escolhemos e o que ganhamos e perdemos com a escolha.

Fazemos isso por dois motivos. Primeiro, para quem chegar depois entender por que o projeto é como é, sem precisar perguntar. Segundo, para nós mesmos: daqui a seis meses é fácil esquecer por que descartamos uma ideia que parece boa.

| Número | Decisão | Quando |
|---|---|---|
| [001](001-sensor-laser-no-lugar-do-ultrassom.md) | Sensor a laser no lugar do sensor ultrassônico | março de 2026 |
| [002](002-bone-no-lugar-da-viseira.md) | Boné no lugar da viseira e motores perto da nuca | setembro de 2026 |
| [003](003-bateria-14500.md) | Bateria 14500 com carcaça de aço no lugar da bateria mole | setembro de 2026 |
| [004](004-pecas-3d-e-fixacao-no-bone.md) | Peças 3D desenhadas em código e fixação no tecido | setembro de 2026 |
| [005](005-conforto-no-contato-com-a-cabeca.md) | Conforto no que encosta na cabeça | setembro de 2026 |
| [006](006-licencas.md) | Licenças abertas e recíprocas, com proteção da marca | setembro de 2026 |

Para registrar uma decisão nova, copie um arquivo existente, use o próximo número e mantenha as quatro partes: situação, contexto, decisão e consequências.

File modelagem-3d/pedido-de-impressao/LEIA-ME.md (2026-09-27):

# Pedido de impressão 3D

Este é o pacote que mandamos para o serviço de impressão. Comece pela [`ficha-do-pedido.pdf`](ficha-do-pedido.pdf): ela explica o material, a configuração e o que vamos conferir na entrega.

- [`lote-1-teste-de-encaixe/`](lote-1-teste-de-encaixe/): poucas peças, para conferir os encaixes com os componentes reais.
- [`lote-2-kit-completo/`](lote-2-kit-completo/): todas as peças de um boné.

Cada lote tem um arquivo 3MF por material (PETG e TPU), com as peças já distribuídas na mesa, e a pasta `stl` com uma peça por arquivo. O número depois de `_x` no nome é a quantidade.

Para refazer este pacote depois de mudar alguma medida, rode `python3 gerar_pecas.py` e depois `python3 gerar_pedido_impressao.py` na pasta [`codigo/`](../codigo/).

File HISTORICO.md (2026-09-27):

# Histórico do projeto

Aqui contamos a linha do tempo da PróVisão, do primeiro diagnóstico até hoje. As entradas mais recentes ficam no topo. Sempre que um marco tiver foto ou vídeo, colocamos o link junto: toda evidência faz parte da história.

## [Em andamento] V1.5

### 27 de setembro de 2026: o boné tomou forma

- **Trocamos a viseira por um boné de aba curva.** Optamos pelo boné por ser um objeto do dia a dia. Os fios passam por uma canaleta costurada por fora, de ponta a ponta. Contamos o raciocínio na [decisão 002](documentacao/decisoes/002-bone-no-lugar-da-viseira.md).
- **Os motores saíram das têmporas e foram para perto da nuca.** Nas têmporas a vibração causava um desconforto forte.
- **Trocamos a bateria.** Saiu a bateria mole de 300 mAh e entrou uma 14500 com carcaça de aço, proteção interna e fusível rearmável. A autonomia estimada subiu de 3 para cerca de 8 horas ([decisão 003](documentacao/decisoes/003-bateria-14500.md)).
- **Desenhamos todas as peças 3D em código**, com as medidas num único arquivo: case da eletrônica, case da bateria, suportes dos sensores na aba (em três inclinações) e berços dos motores. Um programa confere os encaixes antes de qualquer impressão ([decisão 004](documentacao/decisoes/004-pecas-3d-e-fixacao-no-bone.md)).
- **Modelamos o boné inteiro montado**, com cases, sensores, motores e cabos, e geramos um arquivo 3D que abre no navegador.
- **Cuidamos do conforto.** Nenhuma peça dura encosta na pele: placas internas mais finas com almofada de EVA, berços dos motores em plástico flexível dentro de um bolsinho de tecido ([decisão 005](documentacao/decisoes/005-conforto-no-contato-com-a-cabeca.md)).
- **Preparamos o pedido de impressão 3D** em dois lotes (um para testar os encaixes e o kit completo) e a lista de compras com as metragens de fio.
- **Reorganizamos o repositório** com pastas em português e reescrevemos a documentação para ficar mais fácil de entender.
- **Organizamos o acervo de fotos e vídeos** dos principais momentos do projeto: reduzimos as fotos, transformamos os vídeos em GIFs curtos e colocamos cada registro na sua data nesta linha do tempo.
- **Revisamos as licenças.** Percebemos que as licenças escolhidas em julho deixavam qualquer pessoa copiar e vender o projeto. Optamos por licenças abertas e recíprocas (GPL 3.0 no programa, CERN-OHL-S 2.0 na eletrônica e nas peças, CC BY-NC-SA 4.0 na documentação), separamos um arquivo de licença por área e decidimos registrar as marcas no INPI ([decisão 006](documentacao/decisoes/006-licencas.md)).

### 17 de setembro de 2026: a PróVisão na feira de profissões

- A coordenação dos cursos de Ciência da Computação e de Análise e Desenvolvimento de Sistemas da UniFavip Wyden nos convidou para expor a PróVisão na feira de profissões da faculdade, com uma palestra sobre a trajetória do projeto.
- Na palestra, contamos o caminho desde o começo: o problema dos obstáculos altos que a bengala não alcança, a parceria com a ACACE, o protótipo V1 na viseira e a construção do boné da V1.5.
- Levamos a viseira da V1 para a mesa, porque o boné da V1.5 ainda está em construção, e projetamos o site da Horizonte enquanto falávamos. Depois da palestra, estudantes visitantes vieram ver o protótipo de perto.

<p>
  Laboratório de informática com estudantes sentados nos computadores assistindo à palestra. À esquerda, um integrante da equipe fala em pé, ao lado do notebook e do protótipo V1 sobre a mesa
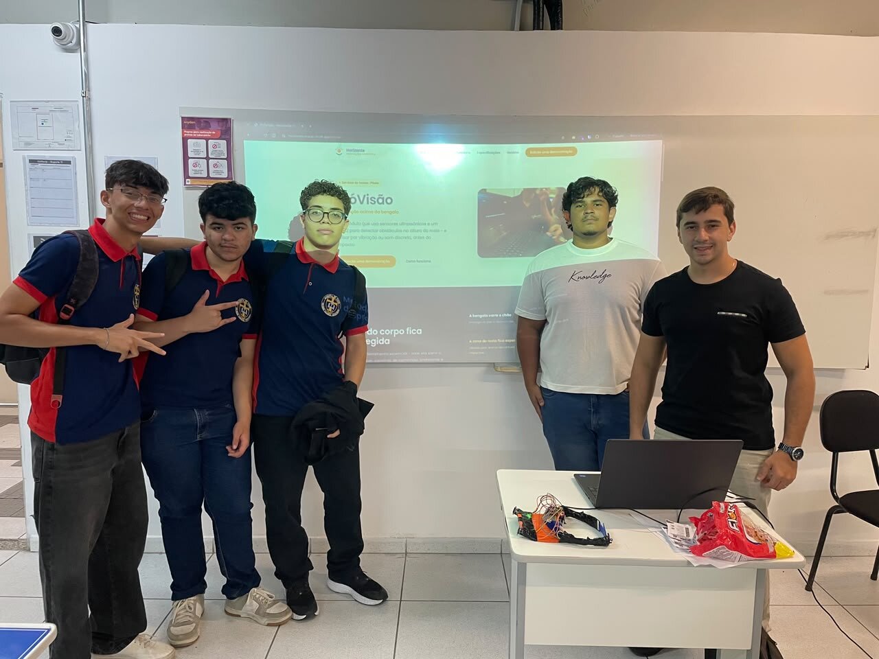
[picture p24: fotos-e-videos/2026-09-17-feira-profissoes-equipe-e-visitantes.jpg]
Dois integrantes da equipe e três estudantes visitantes de uniforme escolar posam em frente à projeção do site da PróVisão. Na mesa, o notebook e a viseira do protótipo V1
  
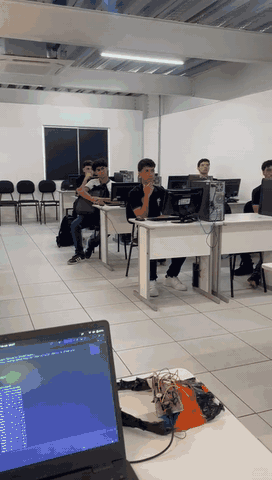
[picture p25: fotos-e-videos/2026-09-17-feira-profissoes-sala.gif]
GIF sem som: a câmera passa pelos estudantes no laboratório, mostra o protótipo V1 na mesa e termina na projeção do site da PróVisão
  
</p>

*A palestra no laboratório, a equipe com estudantes visitantes em frente à projeção do site e um passeio rápido pela sala. Outras fotos da palestra estão em [`fotos-e-videos/`](fotos-e-videos/).*

### Início da V1.5

- Começamos a construção da V1.5: sair da placa de testes para uma placa soldada e peças impressas em 3D, seguindo o plano de ação e o guia de construção do grupo.
- Definimos as correções de segurança elétrica: ajuste da corrente de carga, capacitores para a placa não reiniciar quando os motores ligam, limite de força nos motores e alerta sonoro quando um sensor falha.
- Publicamos o programa da V1.5 em `firmware/src/`, com níveis de vibração bem separados e recuperação de falha. A V1 original continua guardada em `firmware/legado/`.

<!-- [MÍDIA] adicionar fotos da bancada de construção da V1.5 conforme o trabalho avançar -->

## 11 de julho de 2026: decisões de produto

- O projeto ganhou nome: **PróVisão**, primeiro produto da Horizonte Inovação Assistiva.
- Definimos as licenças: MIT para o programa, CERN-OHL-P 2.0 para a eletrônica e as peças, CC BY-SA 4.0 para a documentação.
- Consolidamos a identidade visual do manual de marca: Petróleo `#1B6C79`, Coral `#E07A5F`, Âmbar Sol `#EBA84C` e a fonte Poppins.
- Decidimos que a validação acontece em percurso interno ou na sombra, respeitando o limite do sensor sob sol direto.

## Maio de 2026: validação e encerramento da disciplina

- Apresentamos o projeto na disciplina de Programação de Microcontroladores (UniFavip Wyden) e **recebemos a nota máxima**.
- Entregamos o relatório final de extensão à coordenação.

<p>
  GIF sem som: na sala de aula, um integrante sentado usa a viseira com os sensores enquanto outro explica o funcionamento e aponta para a aba. Outras duas pessoas acompanham em pé
  GIF sem som: um integrante sentado usa a viseira com os sensores enquanto outro aproxima a mão aberta dos lados da cabeça dele, simulando um obstáculo na altura da cabeça
</p>

*À esquerda, a apresentação do protótipo na avaliação da disciplina. À direita, a demonstração: a mão chega perto da cabeça como se fosse um obstáculo alto, para a viseira acusar a aproximação.*

<!-- [MÍDIA] adicionar registros da atividade com a ACACE neste período, se existirem (somente com autorização de imagem) -->

## Abril de 2026: protótipo físico

- Montamos o circuito na placa de testes e prendemos na aba da viseira. Integramos o programa na ESP32-C3 e calibramos distância e tempo de resposta.
- Fizemos o primeiro contato de alinhamento com a ACACE e formalizamos a parceria (Carta de Apresentação e Termo de Aceite, em 30/04/2026).
- Aprendemos uma lição importante: a fixação com fita e fios expostos serviu para demonstrar, mas não é segura nem confortável para um teste com usuários reais. Foi daí que nasceu a V1.5.

<p>
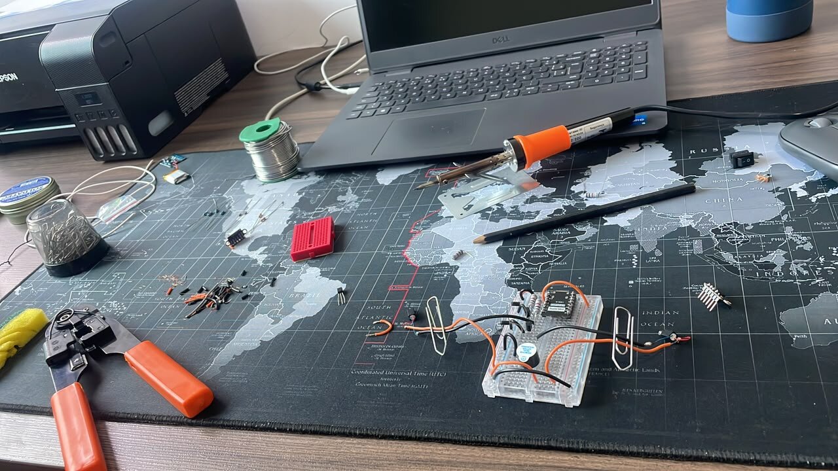
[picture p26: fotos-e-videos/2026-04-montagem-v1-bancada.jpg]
Bancada vista de cima: ferro de solda, alicate, rolo de estanho e componentes espalhados ao redor de uma placa de testes com fios laranja, ao lado de um notebook
  
  Foto de cima da bancada: placa ESP32-C3 e fios coloridos numa placa de testes, com os dois sensores a laser roxos ao lado, sobre um mouse pad com mapa-múndi
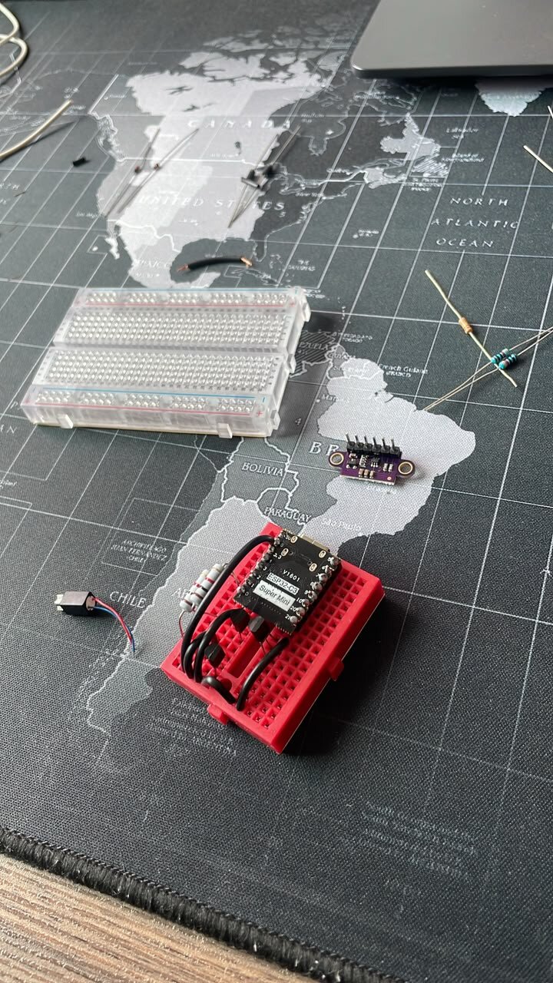
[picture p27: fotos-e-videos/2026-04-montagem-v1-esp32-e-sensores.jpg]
Placa ESP32-C3 encaixada numa mini placa de testes vermelha, com um sensor a laser roxo e uma placa de testes transparente ao lado
  
</p>

*A montagem do protótipo V1 na bancada: a placa ESP32-C3, os dois sensores a laser e a placa de testes.*

<p>
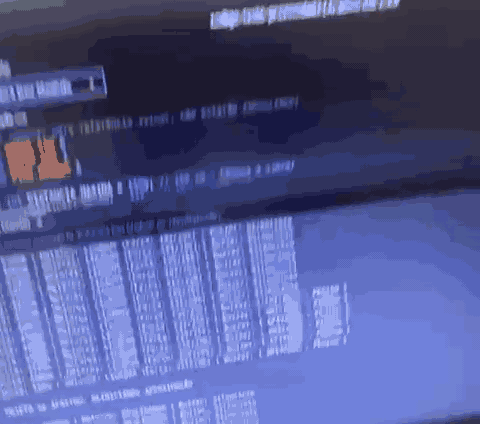
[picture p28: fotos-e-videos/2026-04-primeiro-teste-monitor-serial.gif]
GIF sem som: tela do notebook com o monitor serial mostrando, linha a linha, a distância lida por cada sensor e o estado dos motores e do bipe
  
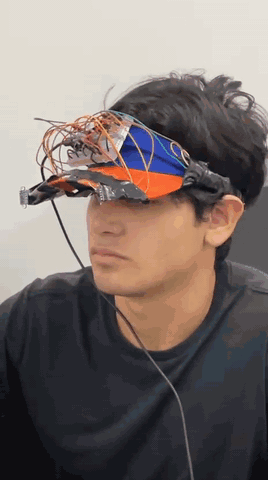
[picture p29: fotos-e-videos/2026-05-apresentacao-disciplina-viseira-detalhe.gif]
GIF sem som: close da viseira azul e laranja na cabeça de um integrante, com os dois sensores, a placa e a fiação colorida presos na aba com fita
  
</p>

*À esquerda, o primeiro teste do programa na placa: o monitor serial mostra a distância de cada sensor e a reação dos motores e do bipe. À direita, o protótipo V1 já preso na viseira (registro feito na apresentação de maio).*

Selfie numa sala da ACACE: dois integrantes da equipe em pé, um deles segurando um documento, e o presidente e a vice-presidente da associação sentados à mesa

*Primeira reunião com a ACACE, com o presidente e a vice-presidente da associação.*

## Março de 2026: especificação e simulação

- Levantamos os requisitos e compramos os componentes, mantendo desde o começo a meta de baixo custo.
- Tomamos uma decisão importante: trocar o sensor ultrassônico HC-SR04 pelos sensores a laser VL53L0X. Ganhamos precisão de milímetros e uma leitura separada para cada lado. Registramos na [decisão 001](documentacao/decisoes/001-sensor-laser-no-lugar-do-ultrassom.md).
- Testamos a lógica num simulador (Wokwi e Tinkercad) antes de montar qualquer coisa.

GIF sem som: simulação no computador de uma placa Arduino Uno ligada a dois sensores ultrassônicos e a um bipe. Um cone azul mostra o sensor da direita detectando um obstáculo virtual

*A primeira lógica rodando no simulador, ainda com os sensores ultrassônicos, antes da troca pelo laser. Também guardamos um [detalhe da simulação](fotos-e-videos/2026-03-simulacao-ultrassom-detalhe.gif) com a distância medida na tela.*

## Fevereiro de 2026: diagnóstico

- Formamos o grupo e definimos o problema: os "obstáculos altos" que a bengala branca não detecta.
- Escolhemos a ACACE (Associação Caruaruense de Cegos e Amblíopes) como parceira e público participante do projeto de extensão.
- Pesquisamos referências em tecnologia assistiva, sistemas embarcados e sensores.

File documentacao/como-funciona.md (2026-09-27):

# Como a PróVisão funciona

Aqui explicamos o caminho completo: da luz que sai do sensor até a vibração que a pessoa sente na nuca. Tentamos escrever para quem nunca mexeu com eletrônica conseguir acompanhar.

## O ciclo de 50 milissegundos

A placa repete o mesmo ciclo 20 vezes por segundo:

1. pergunta a distância para os dois sensores, o da esquerda e o da direita;
2. converte cada distância em um nível de alerta, de 0 (nada) a 3 (forte);
3. liga o motor do lado correspondente na força daquele nível;
4. se qualquer lado estiver abaixo de 30 cm, toca o bipe.

```mermaid
sequenceDiagram
    participant S as Sensores (esquerdo e direito)
    participant P as Placa ESP32-C3
    participant A as Motores e bipe
    loop a cada 50 ms
        P->>S: qual a distância?
        S-->>P: distância em milímetros, de cada lado
        P->>P: distância vira nível de 0 a 3
        P->>A: vibra o motor do mesmo lado
        alt algum lado abaixo de 30 cm
            P->>A: toca o bipe
        end
    end
```

Nesta versão a placa não usa Wi-Fi nem Bluetooth. Deixamos a conexão sem fio para a V2, quando o boné vai registrar dados de uso.

## As peças e o que cada uma faz

**Sensores de distância (VL53L0X).** Cada sensor manda um feixe de luz infravermelha, invisível e seguro para os olhos, e mede quanto tempo ela leva para bater no obstáculo e voltar. É o que chamamos de medição por "tempo de voo". Os dois sensores conversam com a placa pelos mesmos dois fios de dados (a chamada comunicação I²C). Para a placa saber quem é quem, ela dá um endereço diferente para cada sensor toda vez que liga.

**Placa ESP32-C3 Super Mini.** É o cérebro. Ela recebe as distâncias, decide o alerta e comanda motores e bipe. Cabe na ponta de um dedo e custa pouco.

**Motores de vibração.** São iguais aos que fazem um celular vibrar, no formato de uma moeda pequena. A placa controla a força ligando e desligando o motor muito rápido. Quanto mais tempo ligado em cada pulso, mais forte a vibração. Esse controle por pulsos tem o nome técnico de PWM.

**Bipe.** Um pequeno buzzer que toca quando a distância fica perigosa e também avisa quando algo dá errado.

**Bateria e carregador.** Uma bateria de lítio no formato 14500 (do tamanho de uma pilha AA) com proteção interna, carregada por um módulo com entrada USB-C. Contamos por que escolhemos essa bateria em [decisoes/003-bateria-14500.md](decisoes/003-bateria-14500.md).

## Decisões que definem o produto

**Lado do obstáculo = lado da vibração.** O sensor esquerdo comanda o motor esquerdo, e o direito comanda o direito. A pessoa não recebe só um "tem algo perto", recebe "tem algo perto, à esquerda". Essa foi a regra número 1 desde as primeiras conversas com a ACACE.

**Três níveis bem separados em vez de uma rampa.** Na V1 a vibração aumentava aos poucos, conforme a distância diminuía. Na prática, as vibrações mais fracas nem faziam o motor girar, e a pessoa não percebia a diferença entre um nível e outro. Por isso passamos a usar três níveis bem distintos (fraco, médio e forte), com um empurrão curto no início de cada vibração para o motor sair do lugar. Fica mais fácil de sentir e de aprender.

**Motores perto da nuca.** No começo os motores ficavam nas têmporas, mas ali a vibração incomodava bastante. Levamos os dois para a região da nuca, um de cada lado, dentro da faixa interna do boné. O lado continua sendo percebido com clareza. Detalhes em [decisoes/002-bone-no-lugar-da-viseira.md](decisoes/002-bone-no-lugar-da-viseira.md).

**Falha que se escuta.** Se um sensor para de responder, o boné toca bipes de erro e tenta se recuperar sozinho. Concluímos que um equipamento assistivo que falha em silêncio é pior do que não ter equipamento nenhum, porque a pessoa confia num alerta que não vai chegar.

## Distâncias e alertas

Todos esses valores podem ser ajustados em [`firmware/include/config.h`](../firmware/include/config.h).

| Distância até o obstáculo | O que acontece |
|---|---|
| mais de 150 cm | nada |
| de 100 a 150 cm | vibração fraca (nível 1) |
| de 50 a 100 cm | vibração média (nível 2) |
| menos de 50 cm | vibração forte (nível 3) |
| menos de 30 cm | bipe, de qualquer lado |

## Limites que conhecemos

Preferimos deixar claro o que o boné ainda não faz bem:

- **Sol direto.** O sensor trabalha com luz infravermelha, e o sol tem muita luz infravermelha. Debaixo de sol forte o alcance cai de uns 2 m para algo entre 60 e 80 cm. Por isso os testes de campo acontecem em ambiente interno ou na sombra. Resolver o uso ao ar livre é meta da V3.
- **Área coberta.** Cada sensor enxerga um cone de uns 25 graus. A inclinação dos suportes na aba define o que fica coberto à frente, e vamos medir essa cobertura no roteiro de testes.
- **Autonomia.** Estimamos cerca de 8 horas de uso contínuo com a bateria 14500. Esse número ainda é uma conta no papel e vamos medir de verdade nos testes.

## Energia

A bateria fica num case do lado direito do boné e o cabo dela contorna a nuca até o case da eletrônica, do lado esquerdo. Lá, o carregador USB-C cuida da carga e da proteção, e a chave liga/desliga corta a energia do resto do circuito. O carregador foi ajustado para carregar a cerca de 400 mA, que é o recomendado para essa bateria.

A regra mais importante: **nunca carregar com o boné na cabeça.** As outras regras estão em [seguranca.md](seguranca.md).

<!-- [MÍDIA] adicionar aqui o diagrama de blocos desenhado pelo grupo e a foto da placa soldada da V1.5 quando estiver pronta -->

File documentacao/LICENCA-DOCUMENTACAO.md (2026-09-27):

# Licença da documentação, das fotos e dos vídeos: CC BY-NC-SA 4.0

A documentação da PróVisão está sob a **Creative Commons Atribuição-NãoComercial-CompartilhaIgual 4.0 Internacional (CC BY-NC-SA 4.0)**. Isso vale para as pastas `documentacao/` e `fotos-e-videos/` e para os arquivos `README.md`, `HISTORICO.md` e `CONTRIBUTING.md` da raiz. Os textos que explicam o circuito e as peças, dentro de `eletronica/` e `modelagem-3d/`, seguem a licença do hardware, porque fazem parte do projeto técnico. O `README.md` de `firmware/` segue a licença do programa.

Em resumo, qualquer pessoa pode copiar, adaptar e redistribuir este material, desde que cumpra três condições:

- **Atribuição (BY):** dar o crédito à equipe, indicar o link da licença e dizer se fez mudanças.
- **NãoComercial (NC):** não usar o material com o objetivo principal de ganhar dinheiro.
- **CompartilhaIgual (SA):** publicar as adaptações sob esta mesma licença.

Para usar a documentação de forma comercial, fale com a gente pelo e-mail que está no [CONTRIBUTING.md](../CONTRIBUTING.md).

Três observações importantes:

1. **Nome e logo ficam de fora.** O logo da Horizonte Inovação Assistiva (`fotos-e-videos/logo-horizonte.png`) e os nomes PróVisão e Horizonte Inovação Assistiva não estão sob esta licença. A própria licença diz que direitos de marca não são licenciados (seção 2(b)(2)).
2. **Direito autoral não é direito de imagem.** A licença cobre as fotos e os vídeos como obra, mas não autoriza o uso da imagem das pessoas que aparecem neles (seção 2(b)(1)). Para reutilizar uma foto com pessoas, é preciso a autorização delas.
3. **O que já foi publicado continua valendo.** As versões publicadas antes de setembro de 2026 saíram sob CC BY-SA 4.0, que permite uso comercial. Quem obteve aquelas versões continua podendo usá-las nessas condições. O motivo da troca está na [decisão 006](decisoes/006-licencas.md).

Resumo oficial em português: <https://creativecommons.org/licenses/by-nc-sa/4.0/deed.pt-br>

SPDX-License-Identifier: CC-BY-NC-SA-4.0

Copyright (c) 2026 Edson Gabriel Soares da Fonseca, João Luiz Pereira Filho, Nadson Alex da Silva, equipe da Horizonte Inovação Assistiva.

O texto oficial, em inglês, está abaixo.

Creative Commons Attribution-NonCommercial-ShareAlike 4.0 International

 Creative Commons Corporation (“Creative Commons”) is not a law firm and does not provide legal services or legal advice. Distribution of Creative Commons public licenses does not create a lawyer-client or other relationship. Creative Commons makes its licenses and related information available on an “as-is” basis. Creative Commons gives no warranties regarding its licenses, any material licensed under their terms and conditions, or any related information. Creative Commons disclaims all liability for damages resulting from their use to the fullest extent possible.

Using Creative Commons Public Licenses

Creative Commons public licenses provide a standard set of terms and conditions that creators and other rights holders may use to share original works of authorship and other material subject to copyright and certain other rights specified in the public license below. The following considerations are for informational purposes only, are not exhaustive, and do not form part of our licenses.

Considerations for licensors: Our public licenses are intended for use by those authorized to give the public permission to use material in ways otherwise restricted by copyright and certain other rights. Our licenses are irrevocable. Licensors should read and understand the terms and conditions of the license they choose before applying it. Licensors should also secure all rights necessary before applying our licenses so that the public can reuse the material as expected. Licensors should clearly mark any material not subject to the license. This includes other CC-licensed material, or material used under an exception or limitation to copyright. More considerations for licensors.

Considerations for the public: By using one of our public licenses, a licensor grants the public permission to use the licensed material under specified terms and conditions. If the licensor’s permission is not necessary for any reason–for example, because of any applicable exception or limitation to copyright–then that use is not regulated by the license. Our licenses grant only permissions under copyright and certain other rights that a licensor has authority to grant. Use of the licensed material may still be restricted for other reasons, including because others have copyright or other rights in the material. A licensor may make special requests, such as asking that all changes be marked or described. Although not required by our licenses, you are encouraged to respect those requests where reasonable. More considerations for the public.

Creative Commons Attribution-NonCommercial-ShareAlike 4.0 International Public License

By exercising the Licensed Rights (defined below), You accept and agree to be bound by the terms and conditions of this Creative Commons Attribution-NonCommercial-ShareAlike 4.0 International Public License ("Public License"). To the extent this Public License may be interpreted as a contract, You are granted the Licensed Rights in consideration of Your acceptance of these terms and conditions, and the Licensor grants You such rights in consideration of benefits the Licensor receives from making the Licensed Material available under these terms and conditions.

Section 1 – Definitions.

     a.	Adapted Material means material subject to Copyright and Similar Rights that is derived from or based upon the Licensed Material and in which the Licensed Material is translated, altered, arranged, transformed, or otherwise modified in a manner requiring permission under the Copyright and Similar Rights held by the Licensor. For purposes of this Public License, where the Licensed Material is a musical work, performance, or sound recording, Adapted Material is always produced where the Licensed Material is synched in timed relation with a moving image.

     b.	Adapter's License means the license You apply to Your Copyright and Similar Rights in Your contributions to Adapted Material in accordance with the terms and conditions of this Public License.

     c.	BY-NC-SA Compatible License means a license listed at creativecommons.org/compatiblelicenses, approved by Creative Commons as essentially the equivalent of this Public License.

     d.	Copyright and Similar Rights means copyright and/or similar rights closely related to copyright including, without limitation, performance, broadcast, sound recording, and Sui Generis Database Rights, without regard to how the rights are labeled or categorized. For purposes of this Public License, the rights specified in Section 2(b)(1)-(2) are not Copyright and Similar Rights.

     e.	Effective Technological Measures means those measures that, in the absence of proper authority, may not be circumvented under laws fulfilling obligations under Article 11 of the WIPO Copyright Treaty adopted on December 20, 1996, and/or similar international agreements.

     f.	Exceptions and Limitations means fair use, fair dealing, and/or any other exception or limitation to Copyright and Similar Rights that applies to Your use of the Licensed Material.

     g.	License Elements means the license attributes listed in the name of a Creative Commons Public License. The License Elements of this Public License are Attribution, NonCommercial, and ShareAlike.

     h.	Licensed Material means the artistic or literary work, database, or other material to which the Licensor applied this Public License.

     i.	Licensed Rights means the rights granted to You subject to the terms and conditions of this Public License, which are limited to all Copyright and Similar Rights that apply to Your use of the Licensed Material and that the Licensor has authority to license.

     j.	Licensor means the individual(s) or entity(ies) granting rights under this Public License.

     k.	NonCommercial means not primarily intended for or directed towards commercial advantage or monetary compensation. For purposes of this Public License, the exchange of the Licensed Material for other material subject to Copyright and Similar Rights by digital file-sharing or similar means is NonCommercial provided there is no payment of monetary compensation in connection with the exchange.

     l.	Share means to provide material to the public by any means or process that requires permission under the Licensed Rights, such as reproduction, public display, public performance, distribution, dissemination, communication, or importation, and to make material available to the public including in ways that members of the public may access the material from a place and at a time individually chosen by them.

     m.	Sui Generis Database Rights means rights other than copyright resulting from Directive 96/9/EC of the European Parliament and of the Council of 11 March 1996 on the legal protection of databases, as amended and/or succeeded, as well as other essentially equivalent rights anywhere in the world.

     n.	You means the individual or entity exercising the Licensed Rights under this Public License. Your has a corresponding meaning.

Section 2 – Scope.

     a.	License grant.

          1. Subject to the terms and conditions of this Public License, the Licensor hereby grants You a worldwide, royalty-free, non-sublicensable, non-exclusive, irrevocable license to exercise the Licensed Rights in the Licensed Material to:

               A. reproduce and Share the Licensed Material, in whole or in part, for NonCommercial purposes only; and

               B. produce, reproduce, and Share Adapted Material for NonCommercial purposes only.

          2. Exceptions and Limitations. For the avoidance of doubt, where Exceptions and Limitations apply to Your use, this Public License does not apply, and You do not need to comply with its terms and conditions.

          3. Term. The term of this Public License is specified in Section 6(a).

          4. Media and formats; technical modifications allowed. The Licensor authorizes You to exercise the Licensed Rights in all media and formats whether now known or hereafter created, and to make technical modifications necessary to do so. The Licensor waives and/or agrees not to assert any right or authority to forbid You from making technical modifications necessary to exercise the Licensed Rights, including technical modifications necessary to circumvent Effective Technological Measures. For purposes of this Public License, simply making modifications authorized by this Section 2(a)(4) never produces Adapted Material.

          5. Downstream recipients.

               A. Offer from the Licensor – Licensed Material. Every recipient of the Licensed Material automatically receives an offer from the Licensor to exercise the Licensed Rights under the terms and conditions of this Public License.

               B. Additional offer from the Licensor – Adapted Material. Every recipient of Adapted Material from You automatically receives an offer from the Licensor to exercise the Licensed Rights in the Adapted Material under the conditions of the Adapter’s License You apply.

               C. No downstream restrictions. You may not offer or impose any additional or different terms or conditions on, or apply any Effective Technological Measures to, the Licensed Material if doing so restricts exercise of the Licensed Rights by any recipient of the Licensed Material.

          6. No endorsement. Nothing in this Public License constitutes or may be construed as permission to assert or imply that You are, or that Your use of the Licensed Material is, connected with, or sponsored, endorsed, or granted official status by, the Licensor or others designated to receive attribution as provided in Section 3(a)(1)(A)(i).

     b.	Other rights.

          1. Moral rights, such as the right of integrity, are not licensed under this Public License, nor are publicity, privacy, and/or other similar personality rights; however, to the extent possible, the Licensor waives and/or agrees not to assert any such rights held by the Licensor to the limited extent necessary to allow You to exercise the Licensed Rights, but not otherwise.

          2. Patent and trademark rights are not licensed under this Public License.

          3. To the extent possible, the Licensor waives any right to collect royalties from You for the exercise of the Licensed Rights, whether directly or through a collecting society under any voluntary or waivable statutory or compulsory licensing scheme. In all other cases the Licensor expressly reserves any right to collect such royalties, including when the Licensed Material is used other than for NonCommercial purposes.

Section 3 – License Conditions.

Your exercise of the Licensed Rights is expressly made subject to the following conditions.

     a.	Attribution.

          1. If You Share the Licensed Material (including in modified form), You must:

               A. retain the following if it is supplied by the Licensor with the Licensed Material:

                    i.	identification of the creator(s) of the Licensed Material and any others designated to receive attribution, in any reasonable manner requested by the Licensor (including by pseudonym if designated);

                    ii.	a copyright notice;

                    iii. a notice that refers to this Public License;

                    iv.	a notice that refers to the disclaimer of warranties;

                    v.	a URI or hyperlink to the Licensed Material to the extent reasonably practicable;

               B. indicate if You modified the Licensed Material and retain an indication of any previous modifications; and

               C. indicate the Licensed Material is licensed under this Public License, and include the text of, or the URI or hyperlink to, this Public License.

          2. You may satisfy the conditions in Section 3(a)(1) in any reasonable manner based on the medium, means, and context in which You Share the Licensed Material. For example, it may be reasonable to satisfy the conditions by providing a URI or hyperlink to a resource that includes the required information.

          3. If requested by the Licensor, You must remove any of the information required by Section 3(a)(1)(A) to the extent reasonably practicable.

     b.	ShareAlike.In addition to the conditions in Section 3(a), if You Share Adapted Material You produce, the following conditions also apply.

          1. The Adapter’s License You apply must be a Creative Commons license with the same License Elements, this version or later, or a BY-NC-SA Compatible License.

          2. You must include the text of, or the URI or hyperlink to, the Adapter's License You apply. You may satisfy this condition in any reasonable manner based on the medium, means, and context in which You Share Adapted Material.

          3. You may not offer or impose any additional or different terms or conditions on, or apply any Effective Technological Measures to, Adapted Material that restrict exercise of the rights granted under the Adapter's License You apply.

Section 4 – Sui Generis Database Rights.

Where the Licensed Rights include Sui Generis Database Rights that apply to Your use of the Licensed Material:

     a.	for the avoidance of doubt, Section 2(a)(1) grants You the right to extract, reuse, reproduce, and Share all or a substantial portion of the contents of the database for NonCommercial purposes only;

     b.	if You include all or a substantial portion of the database contents in a database in which You have Sui Generis Database Rights, then the database in which You have Sui Generis Database Rights (but not its individual contents) is Adapted Material, including for purposes of Section 3(b); and

     c.	You must comply with the conditions in Section 3(a) if You Share all or a substantial portion of the contents of the database.
For the avoidance of doubt, this Section 4 supplements and does not replace Your obligations under this Public License where the Licensed Rights include other Copyright and Similar Rights.

Section 5 – Disclaimer of Warranties and Limitation of Liability.

     a.	Unless otherwise separately undertaken by the Licensor, to the extent possible, the Licensor offers the Licensed Material as-is and as-available, and makes no representations or warranties of any kind concerning the Licensed Material, whether express, implied, statutory, or other. This includes, without limitation, warranties of title, merchantability, fitness for a particular purpose, non-infringement, absence of latent or other defects, accuracy, or the presence or absence of errors, whether or not known or discoverable. Where disclaimers of warranties are not allowed in full or in part, this disclaimer may not apply to You.

     b.	To the extent possible, in no event will the Licensor be liable to You on any legal theory (including, without limitation, negligence) or otherwise for any direct, special, indirect, incidental, consequential, punitive, exemplary, or other losses, costs, expenses, or damages arising out of this Public License or use of the Licensed Material, even if the Licensor has been advised of the possibility of such losses, costs, expenses, or damages. Where a limitation of liability is not allowed in full or in part, this limitation may not apply to You.

     c.	The disclaimer of warranties and limitation of liability provided above shall be interpreted in a manner that, to the extent possible, most closely approximates an absolute disclaimer and waiver of all liability.

Section 6 – Term and Termination.

     a.	This Public License applies for the term of the Copyright and Similar Rights licensed here. However, if You fail to comply with this Public License, then Your rights under this Public License terminate automatically.

     b.	Where Your right to use the Licensed Material has terminated under Section 6(a), it reinstates:

          1.	automatically as of the date the violation is cured, provided it is cured within 30 days of Your discovery of the violation; or

          2.	upon express reinstatement by the Licensor.

     For the avoidance of doubt, this Section 6(b) does not affect any right the Licensor may have to seek remedies for Your violations of this Public License.

     c.	For the avoidance of doubt, the Licensor may also offer the Licensed Material under separate terms or conditions or stop distributing the Licensed Material at any time; however, doing so will not terminate this Public License.

     d.	Sections 1, 5, 6, 7, and 8 survive termination of this Public License.

Section 7 – Other Terms and Conditions.

     a.	The Licensor shall not be bound by any additional or different terms or conditions communicated by You unless expressly agreed.

     b.	Any arrangements, understandings, or agreements regarding the Licensed Material not stated herein are separate from and independent of the terms and conditions of this Public License.

Section 8 – Interpretation.

     a.	For the avoidance of doubt, this Public License does not, and shall not be interpreted to, reduce, limit, restrict, or impose conditions on any use of the Licensed Material that could lawfully be made without permission under this Public License.

     b.	To the extent possible, if any provision of this Public License is deemed unenforceable, it shall be automatically reformed to the minimum extent necessary to make it enforceable. If the provision cannot be reformed, it shall be severed from this Public License without affecting the enforceability of the remaining terms and conditions.

     c.	No term or condition of this Public License will be waived and no failure to comply consented to unless expressly agreed to by the Licensor.

     d.	Nothing in this Public License constitutes or may be interpreted as a limitation upon, or waiver of, any privileges and immunities that apply to the Licensor or You, including from the legal processes of any jurisdiction or authority.

Creative Commons is not a party to its public licenses. Notwithstanding, Creative Commons may elect to apply one of its public licenses to material it publishes and in those instances will be considered the “Licensor.” Except for the limited purpose of indicating that material is shared under a Creative Commons public license or as otherwise permitted by the Creative Commons policies published at creativecommons.org/policies, Creative Commons does not authorize the use of the trademark “Creative Commons” or any other trademark or logo of Creative Commons without its prior written consent including, without limitation, in connection with any unauthorized modifications to any of its public licenses or any other arrangements, understandings, or agreements concerning use of licensed material. For the avoidance of doubt, this paragraph does not form part of the public licenses.

Creative Commons may be contacted at creativecommons.org.

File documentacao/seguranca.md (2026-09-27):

# Segurança: leia antes de usar

Escrevemos esta página porque a PróVisão é usada por pessoas que não conseguem conferir, pela visão, o estado do equipamento. Isso muda o nosso nível de exigência. Aqui, segurança não é uma seção obrigatória de manual: é uma regra de projeto.

## O que a PróVisão é (e o que não é)

- É um **protótipo experimental** em fase de validação, que complementa a bengala branca.
- **Não substitui a bengala**, o cão-guia nem nenhum outro recurso de mobilidade que a pessoa já usa. Nos nossos testes, o participante sempre usa a bengala junto com o boné.
- Não é um dispositivo médico certificado. Todo uso acontece em **teste acompanhado**, com uma pessoa da equipe junto, num percurso conhecido e seguro.

## Regras da bateria

Trocamos a bateria da V1 (uma célula mole, tipo "pastilha") por uma bateria 14500 com carcaça de aço e proteção interna. Mesmo assim, algumas regras não mudam:

1. **Nunca carregar com o boné na cabeça.** Carregue com o boné em cima de uma superfície firme e que não pegue fogo, como uma mesa ou um piso.
2. **Carregador esquentando além de morno:** tire da tomada e investigue antes de usar de novo. Ajustamos o carregador para 400 mA, que é a corrente certa para essa bateria.
3. **Bateria amassada, estufada, vazando ou esquentando sozinha:** ela sai de uso na hora e vai para o descarte de pilhas e baterias (ecoponto).
4. **Os furinhos do case da bateria não podem ser tampados.** Eles ficam em cima do polo positivo e apontam para fora da cabeça. Se a bateria algum dia precisar soltar gás, ele sai para longe do usuário.
5. **Nunca soldar com a bateria conectada.** Desencaixe o conector da bateria antes de qualquer solda.
6. **No cabo da bateria existe um fusível que se rearma sozinho.** Se acontecer um curto, ele corta a corrente e volta a funcionar quando esfria. Não retire esse fusível.

## Regra da gravação do programa

A placa ESP32-C3 tem uma entrada USB-C própria, que fica fechada dentro do case de propósito. **Só grave o programa com a chave do boné desligada ou com a bateria desconectada.** Com a chave ligada, a energia do cabo USB encontra a energia da bateria no mesmo circuito, e isso pode danificar a bateria.

## Conforto e higiene

- Nenhuma peça de plástico impresso encosta direto na pele. As placas internas têm uma almofada de EVA, e os motores ficam dentro de um bolsinho de tecido costurado na faixa interna.
- Entre um participante e outro, limpe a faixa interna, as almofadas e os bolsinhos com álcool 70%.
- Depois de cada sessão, **alguém da equipe confere a pele do participante** nos pontos de contato (nuca e laterais da cabeça). A pessoa não consegue ver uma marca vermelha, então essa conferência é nossa.

## Como o boné avisa que algo deu errado

O boné **avisa quando não está protegendo**:

- **dois bipes curtos ao ligar:** tudo pronto;
- **três bipes longos repetidos:** um sensor falhou. O boné fica tentando se recuperar e os bipes param quando ele volta;
- **ligou e ficou em silêncio:** considere o boné desligado ou com defeito, e não use.

## Privacidade nos testes

Dados de pessoas com deficiência são dados pessoais sensíveis pela Lei Geral de Proteção de Dados (LGPD). Por isso, nos testes:

- o participante sempre assina o Termo de Consentimento Livre e Esclarecido antes de começar;
- fotos e vídeos só com autorização de imagem assinada, à parte;
- os resultados são identificados só por um código de sessão (por exemplo, S03). A lista que liga nome e código fica guardada fora deste repositório.

## Encontrou um risco que não mapeamos?

Abra uma Issue com o rótulo `seguranca`. Esse tipo de contribuição passa na frente de qualquer outra.

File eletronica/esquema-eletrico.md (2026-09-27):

# Esquema elétrico da V1.5

Aqui estão todas as ligações do boné. Partimos do circuito que funcionou na placa de testes da V1 e registramos, no fim, o que mudou na V1.5.

Um aviso sobre nomes: na V1 chamávamos a linha que alimenta os motores de "5 V". Com o boné na bateria, essa linha tem a tensão da bateria (de 3,3 a 4,2 V), e os 5 V só existem com o cabo USB ligado. Por isso passamos a chamar essa linha de **linha da bateria**.

## 1. Placa principal

ESP32-C3 Super Mini, encaixada na placa ilhada por duas barras de pinos fêmea. Assim ela sai sem precisar dessoldar.

## 2. Linhas de energia

| Linha | De onde vem | O que alimenta |
|---|---|---|
| Terra (GND) | negativo comum de todo o circuito | tudo |
| Linha da bateria | bateria, depois do carregador e da chave | motores e bipe (pelos transistores) e a entrada de 5 V da placa |
| 3,3 V | regulador interno da placa ESP32-C3 | os dois sensores |

## 3. Caminho da energia, da bateria até a placa

1. **Bateria 14500**, no case do lado direito.
2. **Fusível rearmável de 500 mA** soldado no fio positivo, logo na saída da bateria. Se o cabo entrar em curto, ele corta a corrente.
3. **Cabo de 2 fios** contornando a nuca pela canaleta até o case da esquerda, com um conector JST no final.
4. **Carregador TP4056 USB-C**: a bateria entra nos pontos B+ e B-.
5. **Chave liga/desliga** entre a saída do carregador (OUT+) e a linha da bateria.

**Ajuste obrigatório no carregador:** de fábrica ele carrega a 1 A, forte demais para a bateria 14500. Trocamos o resistor que define a corrente de carga (marcado como R3 ou "Rprog" no módulo) por um de **3 kΩ**, e a carga cai para cerca de 400 mA.

## 4. Pinos da placa ESP32-C3

| Pino | Para que usamos |
|---|---|
| 0 | Motor esquerdo (pelo transistor) |
| 1 | Motor direito (pelo transistor) |
| 3 | Bipe (pelo transistor) |
| 4 | Dados dos sensores (SDA), compartilhado pelos dois |
| 5 | Relógio dos sensores (SCL), compartilhado pelos dois |
| 6 | Liga/desliga do sensor esquerdo (XSHUT) |
| 7 | Liga/desliga do sensor direito (XSHUT) |

## 5. Como a placa liga os motores e o bipe

A placa não fornece corrente suficiente para um motor. Por isso cada motor e o bipe são ligados por um transistor 2N2222, que funciona como um interruptor comandado pela placa:

- pino da placa → resistor de 1 kΩ → perna do meio do transistor (base);
- perna emissora do transistor → terra;
- fio negativo do motor (ou do bipe) → perna coletora do transistor; fio positivo → linha da bateria;
- em cada **motor**, um diodo 1N4148 ligado ao contrário, em paralelo, com a faixa do diodo virada para a linha da bateria. Quando o motor desliga, ele gera um pico de tensão, e o diodo absorve esse pico antes que ele chegue no transistor.

## 6. Sensores VL53L0X

| Pino do sensor | Liga em |
|---|---|
| VIN | 3,3 V |
| GND | terra |
| SDA | pino 4 (os dois sensores no mesmo fio) |
| SCL | pino 5 (os dois sensores no mesmo fio) |
| XSHUT | pino 6 (esquerdo) ou pino 7 (direito) |

As plaquinhas dos sensores já têm os resistores de que a comunicação precisa, então não é preciso colocar nenhum a mais.

Nos cabos dos sensores, torça o fio de dados (amarelo) e o de relógio (verde) junto com o terra (preto). O cabo do sensor direito passa dos 70 cm, e trançar os fios diminui a interferência.

## 7. Cores dos fios que combinamos

| Cor | Uso |
|---|---|
| vermelho | positivo (3,3 V nos sensores, linha da bateria nos motores e bateria) |
| preto | terra |
| amarelo | dados dos sensores (SDA) |
| verde | relógio dos sensores (SCL) |
| azul ou branco | liga/desliga de cada sensor (XSHUT) |

## O que mudou da V1 para a V1.5

1. **Bateria:** saiu a bateria mole de 300 mAh e entrou a 14500 de cerca de 800 mAh, com proteção e fusível rearmável. Explicamos o porquê na [decisão 003](../documentacao/decisoes/003-bateria-14500.md).
2. **Carregador:** resistor de carga trocado para 3 kΩ (cerca de 400 mA) e versão com entrada USB-C.
3. **Capacitores novos:** 470 µF entre a linha da bateria e o terra, perto dos motores, e 100 nF junto de cada conector de sensor. Sem eles, a placa da V1 reiniciava quando os motores ligavam.
4. **Conectores JST** em sensores, motores e bateria, no lugar de solda direta. Dá para tirar a eletrônica do boné para lavar.
5. **Placa ESP32-C3 encaixada** em barras de pinos fêmea, removível.

## Próximo passo planejado

Queremos que o boné avise a carga da bateria por vibração ao ligar. Para isso a placa precisa medir a tensão da bateria com dois resistores de 100 kΩ (que já estão na lista de compras). O pino 2, que parecia o candidato natural, é usado pela placa durante a partida e pode atrapalhar a inicialização. Por isso o plano é **passar o bipe do pino 3 para o pino 10 e usar o pino 3 para medir a bateria**. Essa mudança ainda não foi feita no programa.

## Cuidado ao gravar o programa

A entrada USB-C da própria placa ESP32-C3 fica fechada dentro do case. Com a chave ligada, a energia do cabo USB encontra a linha da bateria. Grave o programa só com a chave desligada ou com a bateria desconectada.

## Registro da montagem

Foto de cima da bancada: placa ESP32-C3 e fios coloridos numa placa de testes, com os dois sensores a laser roxos ao lado, sobre um mouse pad com mapa-múndi

*A montagem da V1 na placa de testes, em abril de 2026. Na V1.5, essa montagem dá lugar a uma placa soldada.*

<!-- [MÍDIA] adicionar a foto da placa soldada da V1.5 quando estiver pronta -->

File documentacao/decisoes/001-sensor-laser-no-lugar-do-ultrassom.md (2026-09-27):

# 001. Sensor a laser no lugar do sensor ultrassônico

**Situação:** aceita · **Data:** março de 2026

## Contexto

No planejamento inicial íamos usar o HC-SR04, o sensor ultrassônico clássico dos projetos com microcontrolador: barato e fácil de achar. Durante a especificação, esbarramos em três problemas para o nosso caso:

1. Ele é grande para a aba de um acessório de cabeça (tem dois "olhos" de 16 mm) e precisaríamos de dois.
2. O som se espalha num cone largo. Fica difícil separar "obstáculo à esquerda" de "obstáculo à direita", e avisar o lado era justamente o que os associados da ACACE mais valorizavam.
3. Em superfícies macias, como roupas e folhas, o eco volta fraco e a leitura fica instável.

## Decisão

Devido a esses três pontos, optamos por dois sensores **VL53L0X**. Eles medem a distância pelo tempo que um feixe de luz infravermelha leva para ir e voltar. Têm precisão de 1 mm, enxergam num cone estreito de uns 25 graus (o que permite uma leitura separada para cada lado) e são minúsculos. Os dois dividem os mesmos fios de comunicação com a placa, e a placa dá um endereço diferente para cada um toda vez que liga.

## Consequências

**O que ganhamos:** precisão de milímetros, noção real de lado e um equipamento menor e mais leve.

**O que aceitamos perder:** sensores de luz infravermelha perdem alcance sob sol direto (de uns 2 m para algo entre 60 e 80 cm). Por isso a validação de campo acontece em ambiente interno ou na sombra, e colocamos o uso ao ar livre como meta da V3, em vez de fingir que esse limite não existe.

Essa troca também mudou o formato do produto: os sensores pequenos permitiram sair dos "óculos" e ir para uma viseira. Mais tarde, a viseira virou boné (veja a [decisão 002](002-bone-no-lugar-da-viseira.md)).

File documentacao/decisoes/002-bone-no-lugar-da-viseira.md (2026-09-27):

# 002. Boné no lugar da viseira e motores perto da nuca

**Situação:** aceita · **Data:** setembro de 2026

## Contexto

A V1 foi montada numa viseira, com os fios presos por fita. Funcionou bem para a apresentação em sala, mas percebemos dois problemas para o teste com usuários reais:

1. A viseira não é um acessório comum no dia a dia. Quem usa o equipamento acaba andando com algo que chama atenção.
2. Os motores de vibração ficavam nas têmporas, e ali a vibração causava um desconforto forte.

## Decisão

Optamos pelo **boné de aba curva com regulagem atrás**, porque é um objeto que as pessoas já usam no dia a dia e porque a aba é um lugar natural para os sensores.

Junto com o boné, definimos:

- **Motores perto da nuca**, um de cada lado, dentro da faixa interna do boné (a carneira). O lado da vibração continua claro e o incômodo das têmporas some.
- **Uma canaleta costurada por fora**, de ponta a ponta do boné, por onde passam os fios dos sensores, dos motores e da bateria. Os fios ficam protegidos e o boné fica com acabamento limpo.
- **Dois cases em laterais opostas**: o da eletrônica do lado esquerdo e o da bateria do lado direito. Concluímos essa divisão por dois motivos: o peso fica equilibrado e a bateria fica longe da placa.
- **Sensores na aba**, 50 mm para cada lado do centro e um pouco atrás da borda, que protege o suporte de batidas de frente.

## Consequências

**O que ganhamos:** um produto mais discreto, fios protegidos, peso equilibrado e vibração sem incômodo.

**O que aceitamos:** o case da eletrônica fica entre 26 e 31 mm saltado da lateral do boné. Com a placa de circuito própria da V2, essa altura vai diminuir bastante. Além disso, cada modelo de boné tem uma curva diferente, então é preciso medir o boné real antes da impressão final (explicamos como em [`modelagem-3d/README.md`](../../modelagem-3d/README.md)).

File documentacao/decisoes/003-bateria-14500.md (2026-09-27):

# 003. Bateria 14500 com carcaça de aço

**Situação:** aceita · **Data:** setembro de 2026

## Contexto

A V1 usava uma bateria de lítio de 300 mAh do tipo "pastilha" (em inglês, pouch): uma célula mole, embalada num filme parecido com papel alumínio. Esse tipo de bateria é leve, mas é o mais sensível a pancada, dobra e perfuração, e pode estufar. Num equipamento que fica na cabeça, e usado por quem não consegue ver se a bateria está estufando, esse risco não é aceitável. Além disso, 300 mAh dava só umas 3 horas de uso.

Comparamos quatro opções:

| Opção | Tamanho e peso | Autonomia estimada | Mudança no circuito |
|---|---|---|---|
| **Lítio 14500 com proteção, ~800 mAh** | tamanho de uma pilha AA, ~20 g | ~8 horas | quase nenhuma |
| Lítio-ferro-fosfato 14500, 600 mAh | igual | ~6 horas | grande (outro carregador) |
| Lítio-ferro-fosfato 18650, ~1500 mAh | 18 x 65 mm, ~40 g | ~15 horas | grande |
| Pilhas AA comuns ou recarregáveis | três pilhas, ~70 g | varia | não recomendado: volume grande e a alcalina pode vazar líquido |

## Decisão

Optamos pela **bateria 14500 de lítio com placa de proteção e terminais para solda**, presa dentro do case da bateria e sem troca pelo usuário. Concluímos essa escolha por três motivos:

1. A carcaça é de aço e já vem com válvula de alívio e corte interno. Isso resolve o risco de pancada e perfuração.
2. O carregador que já usávamos (TP4056) continua servindo, só trocando um resistor para carregar a 400 mA, que é o recomendado para essa bateria.
3. A autonomia sobe de 3 para cerca de 8 horas, sem aumentar muito o tamanho.

Junto com ela colocamos um **fusível que se rearma sozinho** no fio positivo, para proteger contra curto no cabo que atravessa o boné.

## Consequências

**O que ganhamos:** muito mais segurança mecânica, mais autonomia e quase nenhuma mudança na eletrônica.

**O que aceitamos:** a bateria pesa uns 14 g a mais que a antiga. A química lítio-ferro-fosfato é ainda mais estável, mas exigiria outro carregador e outra forma de alimentar a placa. Deixamos essa opção para estudar na V2, junto com a placa de circuito própria.

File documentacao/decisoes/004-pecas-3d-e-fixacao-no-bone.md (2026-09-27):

# 004. Peças 3D desenhadas em código e fixação no tecido

**Situação:** aceita · **Data:** setembro de 2026

## Contexto

Para o teste de campo precisávamos de cases para a eletrônica e para a bateria, suportes para os sensores na aba e berços para os motores. Tudo isso precisa se encaixar em componentes que ainda vamos medir com paquímetro, e em bonés que mudam de curva de um modelo para outro.

## Decisão

**Desenhamos as peças em código (Python, com a biblioteca CadQuery) em vez de desenhar à mão num programa de CAD.** Todas as medidas ficam num único arquivo, [`medidas.py`](../../modelagem-3d/codigo/pecas/medidas.py). Quando alguém mede um componente e a medida real é diferente, basta trocar o número e gerar as peças de novo. Um programa de verificação confere se alguma peça atravessa outra antes de qualquer impressão.

**A fixação no boné é um "sanduíche" através do tecido.** Por fora fica o case sobre uma base curva que acompanha a copa. Por dentro fica uma placa fina. Parafusos M2 atravessam o tecido e prendem as duas. Os parafusos ficam do lado de dentro, com a cabeça rente à placa, e nenhum deles fica perto da bateria.

**A base curva do case da eletrônica é uma peça separada.** Se o boné mudar, reimprimimos só a base, não o case inteiro.

**Os suportes dos sensores saem em três inclinações (0, 10 e 20 graus).** A aba aponta para baixo quando o boné está na cabeça, e o ângulo muda de pessoa para pessoa. No primeiro teste escolhemos a inclinação que deixa o sensor olhando reto para a frente.

**Padronizamos um único tamanho de parafuso (M2)** no projeto inteiro. Fica mais fácil comprar e montar.

## Consequências

**O que ganhamos:** peças que se ajustam trocando números, verificação automática de encaixe, arquivos abertos em formatos que qualquer programa de 3D lê e um pedido de impressão pronto para mandar a qualquer serviço.

**O que aceitamos:** para mexer na modelagem é preciso rodar Python. Para quem só quer ver ou medir, deixamos os arquivos prontos para abrir no FreeCAD, no Fusion ou no navegador.

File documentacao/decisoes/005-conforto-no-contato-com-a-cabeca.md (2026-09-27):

# 005. Conforto no que encosta na cabeça

**Situação:** aceita · **Data:** setembro de 2026

## Contexto

Duas peças ficam do lado de dentro do boné, encostando na cabeça: as placas internas que prendem os cases e os berços dos motores. As duas são de plástico impresso, que tem cantos e marcas de camada. Os motores ainda precisam de contato firme, porque vibração sem contato não é sentida.

## Decisão

Seguimos uma regra só: **o plástico dá a estrutura e uma camada macia faz o contato com a pele.** Na prática:

**Placas internas**

- Ficaram mais finas (1,6 mm em vez de 2 mm) para se moldarem melhor à cabeça.
- A borda ficou toda arredondada.
- Recebem uma almofada de EVA de 3 mm colada do lado da cabeça, cobrindo também as cabeças dos parafusos.
- A parte de baixo da placa entra por trás da faixa interna do boné, que já é feita para encostar na testa.

**Berços dos motores**

- Passaram a ser impressos em TPU, um plástico flexível que cede e acompanha a curva da nuca.
- Ficaram mais baixos (3,4 mm em vez de 4,4 mm) e com uma aba maior (28 mm), para espalhar a pressão.
- O motor entra sob pressão no berço e fica só 0,3 mm para fora.
- Em volta do motor vai um anel de EVA de 2 mm.
- Tudo isso fica dentro de um bolsinho de tecido costurado na faixa interna. A pele encosta só no tecido, e a vibração passa por ele sem perder força.

## O que avaliamos e não fizemos

Pensamos em descer os cases uns 10 mm para a placa interna ficar inteira atrás da faixa interna. Descartamos porque a faixa tem 30 mm de altura e a placa tem 41 mm: mesmo descendo, uma parte ficaria de fora. E o case encostaria na canaleta dos fios. A almofada de EVA resolve o contato sem mexer na posição.

## Consequências

**O que ganhamos:** nenhuma peça dura em contato direto com a pele, pressão espalhada e peças fáceis de limpar com álcool 70%.

**O que aceitamos:** a lista de compras ganhou folhas de EVA e retalhos de tecido, e o berço do motor precisa ser impresso em TPU, que nem todo serviço de impressão tem. No teste de campo vamos medir o conforto aos 15 e aos 30 minutos e conferir a pele depois de cada sessão (veja o [roteiro de testes](../protocolo-de-testes.md)).

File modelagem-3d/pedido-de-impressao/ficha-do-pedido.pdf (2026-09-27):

# PróVisão V1.5

### Pedido de impressão 3D · peças do boné

Horizonte Inovação Assistiva Revisão 3 · 27/09/2026

Arquivos gerados a partir da modelagem do repositório (modelagem-3d). Medidas em milímetros. | Página 1

# 1. Objeto do pedido

Impressão 3D das peças estruturais da PróVisão V1.5, dispositivo assistivo em formato de boné que alerta pessoas com deficiência visual sobre obstáculos na altura da cabeça. As peças fixam os componentes eletrônicos ao boné. O pedido divide-se em dois lotes: o Lote 1 destina-se à verificação dos encaixes e o Lote 2 corresponde ao conjunto completo de uma unidade. Todas as peças foram projetadas para impressão sem estruturas de suporte.

Solicitante | __________________________________________________________
Contato (telefone ou e-mail) | __________________________________________________________
Prestador do serviço | __________________________________________________________
Prazo de entrega | __________________________________________________________
Cor do PETG | ____________________ (preferência: preto ou petróleo, #1B6C79)
Lote solicitado | [ ] Lote 1: verificação de encaixe (8 peças, aprox. 64 g) [ ] Lote 2: conjunto completo de uma unidade (19 peças, aprox. 129 g)

# 2. Especificações de impressão

Material | PETG nas peças estruturais. O PLA não é aceito, pois as peças ficam expostas ao sol e ao calor da cabeça, condição em que o PLA perde rigidez. TPU 95A (material flexível) somente no berço do motor (M1), que fica em contato com a nuca.
Bico e altura de camada | Bico de 0,4 mm e camada de 0,2 mm.
Paredes | 4 perímetros, necessários para a fixação dos parafusos M2 e para a resistência a impactos.
Topo e fundo | 5 camadas superiores e 4 inferiores.
Preenchimento | 25%, padrão giroide. Na base curva (A3), admite-se 15%.
Suporte | Não utilizar. Todas as peças foram projetadas para impressão sem suporte.
Orientação na mesa | Manter a orientação dos arquivos fornecidos, que já corresponde à posição de impressão. Não rotacionar as peças, em especial a B1 (impressa na vertical) e a A2 (impressa invertida).
Adesão | Borda de adesão (brim) de 5 mm somente na B1, devido à altura e à base estreita.
Escala | 100%, em milímetros. A unidade está definida nos arquivos 3MF.
Furos | Não aplicar compensação de furos. Os furos de 1,7 mm recebem parafusos M2 diretamente no plástico. Caso o equipamento tenda a reduzir o diâmetro de furos pequenos, o solicitante deve ser consultado antes da impressão.

# 3. Conteúdo do pacote

ficha-do-pedido.pdf
lote-1-teste-de-encaixe/ lote1_petg.3mf lote1_tpu.3mf stl/
lote-2-kit-completo/ kit_petg.3mf kit_tpu.3mf stl/
Os arquivos 3MF estão separados por material, com as cópias distribuídas em uma mesa de 235 x 235 mm. Para montagem própria da mesa, utilizar os arquivos STL da pasta stl. O número após _x no nome do arquivo indica a quantidade a imprimir.

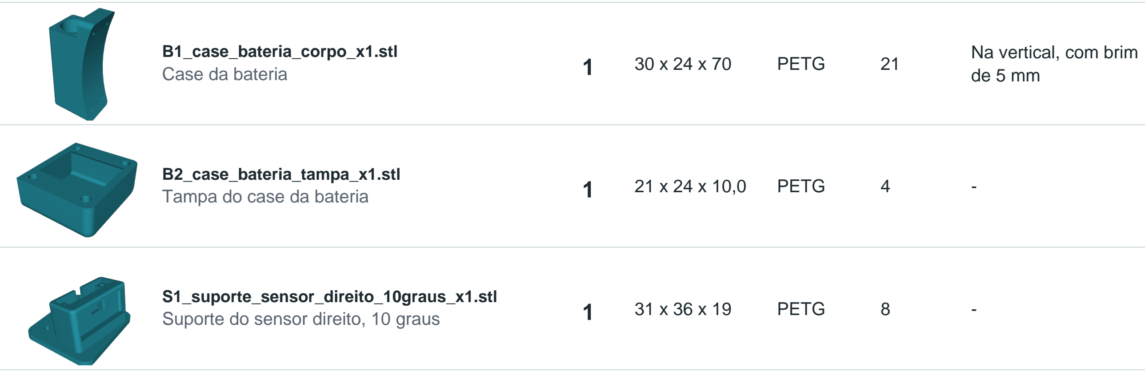
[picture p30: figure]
B1_case_bateria_corpo_x1.stl; Case da bateria; PETG; Na vertical, com brim; B2_case_bateria_tampa_x1.stl; Tampa do case da bateria; S1_suporte_sensor_direito_10graus_x1.stl
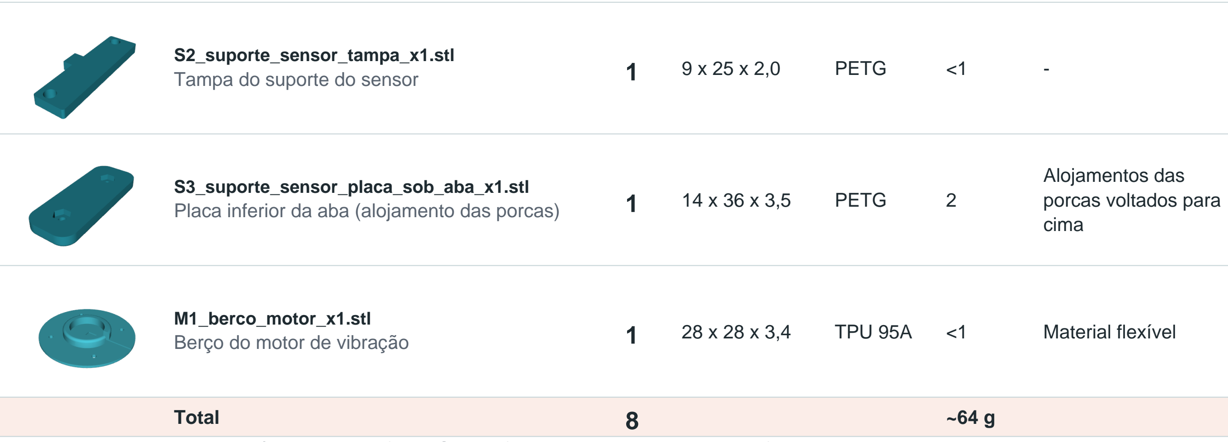
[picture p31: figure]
S2_suporte_sensor_tampa_x1.stl; Tampa do suporte do sensor; PETG; S3_suporte_sensor_placa_sob_aba_x1.stl; Alojamentos das porcas voltados para cima; M1_berco_motor_x1.stl; Berço do motor de vibração; TPU 95A; Material flexível; Total

Arquivos gerados a partir da modelagem do repositório (modelagem-3d). Medidas em milímetros. | Página 2

# 4. Lote 1: verificação de encaixe

Primeira etapa do pedido. Este lote permite verificar, com os componentes reais, o encaixe da placa, do carregador, da bateria, do sensor e do motor antes da impressão do conjunto completo. As peças curvas que dependem das dimensões do boné (base curva e placas internas) constam apenas do Lote 2.

Arquivo e peça | Qtd | Medidas
(mm) | Material | g/un.* | Observação

A1_case_eletronica_corpo_x1.stl
Case da eletrônica | 1 | 75 x 45 x 20 | PETG | 18 | -

A2_case_eletronica_tampa_x1.stl
Tampa do case da eletrônica | 1 | 74 x 45 x 17 | PETG | 10 | Face externa apoiada na mesa
Suporte do sensor direito, 10 graus | 1 | 31 x 36 x 19 | PETG | 8 | -
Placa inferior da aba (alojamento das porcas) | 1 | 14 x 36 x 3,5 | PETG | 2

* Massa estimada com os parâmetros desta ficha. O valor final depende do programa de fatiamento.

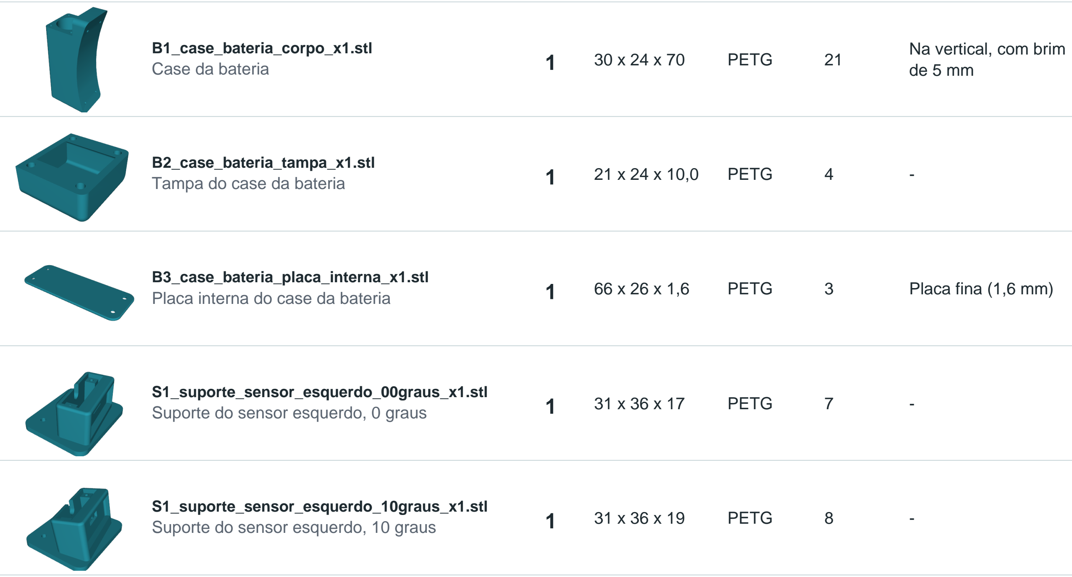
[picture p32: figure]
B1_case_bateria_corpo_x1.stl; Case da bateria; PETG; Na vertical, com brim; B2_case_bateria_tampa_x1.stl; Tampa do case da bateria; B3_case_bateria_placa_interna_x1.stl; S1_suporte_sensor_esquerdo_00graus_x1.stl; S1_suporte_sensor_esquerdo_10graus_x1.stl

Arquivos gerados a partir da modelagem do repositório (modelagem-3d). Medidas em milímetros. | Página 3

# 5. Lote 2: conjunto completo de uma unidade

Todas as peças de uma unidade da PróVisão. Os suportes dos sensores são fornecidos nas três inclinações (0, 10 e 20 graus). A inclinação definitiva será escolhida no primeiro teste com o boné em uso.

Arquivo e peça | Qtd | Medidas
(mm) | Material | g/un.* | Observação

A1_case_eletronica_corpo_x1.stl
Case da eletrônica | 1 | 75 x 45 x 20 | PETG | 18 | -

A2_case_eletronica_tampa_x1.stl
Tampa do case da eletrônica | 1 | 74 x 45 x 17 | PETG | 10 | Face externa apoiada na mesa

A3_case_eletronica_base_curva_x1.stl
Base curva do case da eletrônica | 1 | 74 x 45 x 10 | PETG | 14 | Face plana na mesa

A4_case_eletronica_placa_interna_x1.stl
Placa interna do case da eletrônica | 1 | 68 x 41 x 1,6 | PETG | 6 | Placa fina (1,6 mm)
Placa interna do case da bateria | 1 | 66 x 26 x 1,6 | PETG | 3 | Placa fina (1,6 mm)
Suporte do sensor esquerdo, 0 graus | 1 | 31 x 36 x 17 | PETG | 7 | -
Suporte do sensor esquerdo, 10 graus | 1 | 31 x 36 x 19 | PETG | 8 | -

S1_suporte_sensor_esquerdo_20graus_x1.stl
Suporte do sensor esquerdo, 20 graus | 1 | 32 x 36 x 21 | PETG | 8 | -

S1_suporte_sensor_direito_00graus_x1.stl
Suporte do sensor direito, 0 graus | 1 | 31 x 36 x 17 | PETG | 7 | -

Arquivos gerados a partir da modelagem do repositório (modelagem-3d). Medidas em milímetros. | Página 4
Arquivo e peça | Qtd | Medidas
(mm) | Material | g/un.* | Observação

S1_suporte_sensor_direito_10graus_x1.stl
Suporte do sensor direito, 10 graus | 1 | 31 x 36 x 19 | PETG | 8 | -

S1_suporte_sensor_direito_20graus_x1.stl
Suporte do sensor direito, 20 graus | 1 | 32 x 36 x 21 | PETG | 8 | -

S2_suporte_sensor_tampa_x2.stl
Tampa do suporte do sensor | 2 | 9 x 25 x 2,0 | PETG | <1 | -

S3_suporte_sensor_placa_sob_aba_x2.stl
Placa inferior da aba (alojamento das porcas) | 2 | 14 x 36 x 3,5 | PETG | 2

Alojamentos das
porcas voltados para
cima

M1_berco_motor_x2.stl
Berço do motor de vibração | 2 | 28 x 28 x 3,4 | TPU 95A | <1 | Material flexível
Total | 19 | ~129 g
* Massa estimada com os parâmetros desta ficha. O valor final depende do programa de fatiamento.

# 6. Critérios de aceitação na entrega

- Ausência de resíduos de material no interior dos cases, dos furos e dos recortes (entrada USB-C, chave e entalhes dos cabos).
- Furos de 1,7 mm e de 2,3 mm desobstruídos em toda a extensão, nos pontos em que atravessam a peça.
- Bases planas, sem empenamento. A base curva (A3) e o case da eletrônica (A1) devem assentar um sobre o outro sem folga.
- Boa adesão entre camadas, em especial na B1 (impressa na vertical) e nas colunas da tampa A2.
- Texto em baixo relevo legível na tampa A2 e marcações + e - legíveis na lateral da B1.
- Berços dos motores em TPU flexíveis e sem fiapos.
- Nenhuma peça deve ser lixada, furada ou colada sem consulta prévia ao solicitante, pois as folgas foram dimensionadas para a peça no estado em que sai da impressora.

Dúvidas técnicas sobre as peças devem ser encaminhadas ao contato indicado na página 1.

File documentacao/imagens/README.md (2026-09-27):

# Imagens da documentação

Aqui ficam só as imagens que aparecem no `README.md` e nos documentos desta pasta, já reduzidas para carregar rápido na web. O acervo completo de fotos e vídeos fica em [`fotos-e-videos/`](../../fotos-e-videos/).

As imagens do modelo 3D ficam em [`modelagem-3d/imagens/`](../../modelagem-3d/imagens/), porque são geradas automaticamente a partir dos arquivos de modelagem.

O que já temos e o que ainda falta:

- [ ] `logo-horizonte.png`: logo horizontal (Petróleo + Coral) exportado do manual de marca. O arquivo em `fotos-e-videos/logo-horizonte.png` tem só o símbolo, sem o nome
- [x] `prototipo-em-uso.jpg`: foto principal do README. Por enquanto é um quadro do vídeo da apresentação de maio de 2026, com o protótipo V1 na viseira. Trocamos pela foto do boné da V1.5 quando ele estiver pronto
- [x] `demo.gif`: 7 segundos da viseira V1 com a mão fazendo o papel do obstáculo (cópia de `fotos-e-videos/2026-05-apresentacao-disciplina-demo-obstaculo.gif`). Trocamos por um GIF do boné da V1.5 quando houver vídeo
- [ ] `diagrama-blocos.png`: opcional. O README já desenha o diagrama sozinho, esta versão seria para materiais fora do GitHub

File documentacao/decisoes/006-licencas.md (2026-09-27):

# 006. Licenças abertas e recíprocas, com proteção da marca

**Situação:** aceita · **Data:** setembro de 2026

## Contexto

Queremos garantir que ninguém se aproprie do trabalho técnico da PróVisão. Quando revisamos o repositório com esse objetivo, percebemos que as licenças que escolhemos em julho iam no sentido contrário. MIT no programa, CERN-OHL-P 2.0 na eletrônica e nas peças 3D e CC BY-SA 4.0 na documentação são licenças **permissivas**: deixam qualquer pessoa copiar, modificar e até vender o projeto, desde que mantenha o nosso crédito.

Encontramos também três inconsistências:

1. O arquivo `LICENSE` da raiz trazia a licença MIT sem dizer que ela valia só para o programa da placa. Quem abrisse o repositório no GitHub entenderia que o projeto inteiro era MIT.
2. O README dizia que a documentação estava sob CC BY-SA 4.0, mas não havia no repositório nenhum arquivo com essa licença.
3. Nenhum arquivo de código tinha aviso de autoria e de licença no topo.

Antes de decidir, estudamos o que uma licença consegue e o que ela não consegue fazer:

- **Nenhuma licença impede fisicamente a cópia de um repositório público.** Ela define o que é permitido e dá base para cobrar depois. Os próprios termos de uso do GitHub (seção D.5) deixam qualquer pessoa ver um repositório público e fazer uma cópia dele dentro do site (o chamado fork).
- **O que já publicamos continua valendo.** O repositório está público desde 16 de julho de 2026, e as licenças daquela época não podem ser retiradas de quem obteve os arquivos. A CC BY-SA 4.0 se declara irrevogável e diz que parar de distribuir não encerra a licença (seções 2(a)(1) e 6(c)). A CERN-OHL-P 2.0 ainda concede, a quem recebeu o projeto, uma licença de patente gratuita sobre o que foi publicado (seção 6.1).
- **O direito autoral já existe sem registro.** O programa é protegido por 50 anos, contados a partir do ano seguinte à publicação, e essa proteção independe de registro (Lei 9.609/1998, art. 2º, §§ 2º e 3º). Os textos, as fotos e os desenhos também são protegidos sem registro (Lei 9.610/1998, art. 18). Mas o direito autoral protege a forma, o código e o texto, e não a ideia (Lei 9.610/1998, art. 8º, inciso I). A ideia de um boné com sensores que avisa por vibração só teria proteção com uma patente.

## Decisão

Optamos por manter o projeto aberto, mas **recíproco**, desta versão em diante. Recíproco quer dizer que quem distribuir uma versão modificada precisa devolver as melhorias à comunidade, abertas e sob a mesma licença.

| Parte do projeto | Antes | Agora | Por que escolhemos |
|---|---|---|---|
| Programa da placa (`firmware/`) | MIT | GNU GPL 3.0 (GPL-3.0-only) | Quem distribuir uma versão modificada do programa, inclusive gravada num produto, precisa publicar o código-fonte dela sob a GPL |
| Eletrônica e peças 3D (`eletronica/`, `modelagem-3d/`) | CERN-OHL-P 2.0 | CERN-OHL-S 2.0 | A variante "S", fortemente recíproca, obriga quem fabricar e distribuir um produto baseado no projeto a publicar o projeto completo, com as melhorias |
| Documentação, fotos e vídeos | CC BY-SA 4.0 | CC BY-NC-SA 4.0 | Acrescentamos a cláusula NãoComercial (NC): ninguém pode usar nossos textos e imagens para ganhar dinheiro sem falar com a gente |

Alguns detalhes da decisão:

- **Escolhemos "GPL 3.0 somente" (GPL-3.0-only)** em vez de "GPL 3.0 ou posterior" porque preferimos decidir nós mesmos se vamos adotar uma versão futura da licença.
- **A V1 do programa continua sob MIT.** O arquivo `firmware/legado/viseira_v1.cpp` já foi publicado assim, então guardamos o texto original em `firmware/legado/LICENSE-MIT`. Como a MIT permite incorporar o código num trabalho sob GPL, desde que o aviso dela seja mantido, o programa da V1.5 pode seguir sob GPL.
- **Um arquivo de licença por área.** O `LICENSE` da raiz virou um índice que diz qual licença vale para cada pasta. Os textos completos ficam em `firmware/LICENSE`, `eletronica/LICENCA-HARDWARE.md` (que vale também para `modelagem-3d/`) e `documentacao/LICENCA-DOCUMENTACAO.md`.
- **Avisos de autoria nos arquivos de código.** Colocamos no topo de cada arquivo duas linhas no padrão SPDX, uma forma padronizada de declarar autor e licença que pessoas e ferramentas automáticas conseguem ler.
- **Nome e logo ficam fora das licenças abertas.** Declaramos isso no índice e na licença da documentação.

Decidimos também seguir três proteções que não dependem da licença:

1. **Registrar as marcas PróVisão e Horizonte Inovação Assistiva** no Instituto Nacional da Propriedade Industrial (INPI). É a proteção mais forte contra alguém vender um produto com o nosso nome: o registro garante uso exclusivo em todo o país (Lei 9.279/1996, art. 129) por 10 anos, renováveis (art. 133). Pessoa física tem desconto de 50% nas taxas, mas só pode registrar a marca de uma atividade que exerça de fato (art. 128, § 1º). Por isso precisamos definir antes quem será o titular.
2. **Registrar o programa da placa no INPI.** O registro não é obrigatório, mas serve de prova de autoria se houver disputa na Justiça.
3. **Avaliar, com o núcleo de inovação da faculdade, um pedido de patente de modelo de utilidade.** A patente de modelo de utilidade vale 15 anos e a de invenção vale 20 (Lei 9.279/1996, art. 40). A lei dá 12 meses de "período de graça": uma divulgação feita pelos próprios inventores nos 12 meses anteriores ao pedido não conta contra a novidade (art. 12). Nossas divulgações públicas começaram com a demonstração à ACACE, em abril de 2026, e seguiram na apresentação da disciplina (maio), na publicação no GitHub (16 de julho) e na feira de profissões (17 de setembro). Na contagem mais conservadora, o pedido precisa ser feito até abril de 2027, e a nossa meta é março de 2027. Sabemos que existem produtos parecidos no mercado, então um especialista precisa avaliar se há algo novo o bastante para patentear. E a licença de patente que a CERN-OHL-P concedeu sobre o que publicamos em julho continua valendo para aquela versão.

## O que avaliamos e não fizemos

- **Manter as licenças permissivas.** Descartamos porque elas deixam uma empresa pegar o projeto, fechar as melhorias e vender o resultado sem devolver nada.
- **Código visível com todos os direitos reservados.** Descartamos porque contraria a proposta de hardware aberto que o projeto assumiu desde o começo, afasta quem quer contribuir e, na prática, não impede a cópia, já que o GitHub permite o fork de repositório público.
- **Repositório privado.** Protege mais, mas tira o projeto do alcance de outras pessoas e instituições que poderiam estudá-lo e replicá-lo, o que vai contra a origem do projeto como extensão universitária.

## Consequências

**O que ganhamos:** quem aproveitar a PróVisão num produto distribuído precisa manter o projeto aberto e dar o crédito, a documentação não pode ser vendida por terceiros e cada pasta diz com clareza qual licença vale para ela.

**O que aceitamos:**

- A licença continua sem impedir a cópia: ela só dá base para cobrar depois.
- As versões publicadas até agora seguem sob as licenças permissivas para quem as obteve.
- A GPL e a CERN-OHL-S só exigem abrir as melhorias quando alguém distribui o programa ou o produto. Uma empresa que use uma versão modificada só internamente não precisa publicar nada.
- O GitHub deixa de mostrar uma licença única no topo do repositório, porque o `LICENSE` da raiz agora é um índice.
- Quem contribuir precisa aceitar publicar a contribuição sob a licença da área que alterou. Deixamos isso claro no [CONTRIBUTING.md](../../CONTRIBUTING.md).

## Pendências

- Conferir o regulamento de propriedade intelectual da UniFavip Wyden, porque o projeto nasceu numa disciplina de extensão, e confirmar se ele dá à instituição ou ao orientador algum direito sobre o projeto.
- Conferir os termos assinados com a ACACE (Carta de Apresentação e Termo de Aceite).
- Registrar por escrito a participação do colega que esteve na equipe até a conclusão da disciplina e o acordo dele com a mudança de licença do que ele ajudou a criar.
- Definir quem será o titular das marcas e dos registros no INPI.

Esta análise foi feita pela equipe e não substitui a orientação de um advogado nem do núcleo de inovação da faculdade.

## Fontes

- [Lei 9.279/1996, Lei da Propriedade Industrial](https://www.planalto.gov.br/ccivil_03/leis/l9279.htm)
- [Lei 9.609/1998, Lei do Software](https://www.planalto.gov.br/ccivil_03/leis/l9609.htm)
- [Lei 9.610/1998, Lei de Direitos Autorais](https://www.planalto.gov.br/ccivil_03/leis/l9610.htm)
- [INPI: perguntas frequentes sobre programas de computador](https://www.gov.br/inpi/pt-br/acesso-a-informacao/perguntas-frequentes/programas-de-computador)
- [INPI: descontos nas taxas](https://www.gov.br/inpi/pt-br/servicos/custos-e-pagamento/descontos)
- [Texto da CC BY-SA 4.0](https://creativecommons.org/licenses/by-sa/4.0/legalcode.en) e [da CC BY-NC-SA 4.0](https://creativecommons.org/licenses/by-nc-sa/4.0/legalcode.en)
- [Resumo da CERN-OHL-S 2.0](https://choosealicense.com/licenses/cern-ohl-s-2.0/) e texto da CERN-OHL-P 2.0 publicado em julho (seção 6.1, patentes), guardado no histórico do repositório em `hardware/LICENSE.md`
- [Termos de uso do GitHub, seção D.5](https://docs.github.com/en/site-policy/github-terms/github-terms-of-service)

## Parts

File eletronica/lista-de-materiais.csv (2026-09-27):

Categoria | Item | Quantidade por boné | Comprar (com reserva) | Para que serve | Como procurar na loja | O que conferir | Preço unitário (R$) | Onde compramos
Eletrônica | Placa ESP32-C3 Super Mini (entrada USB-C) | 1 | 2 | O cérebro do boné: lê os sensores e comanda motores e bipe. | ESP32-C3 Super Mini USB-C | Placa de 22 x 18 mm com entrada USB-C. A segunda unidade é reserva.
Eletrônica | Sensor de distância a laser VL53L0X (módulo GY-530) | 2 | 3 | Mede a distância até o obstáculo, um de cada lado da aba. | VL53L0X GY-530 sensor laser | Módulo de cerca de 25 x 11 mm com 6 pinos. Os suportes da aba foram desenhados para ele.
Eletrônica | Motor de vibração tipo moeda 10 mm (3 V) | 2 | 4 | Faz a vibração perto da nuca, um de cada lado. | motor vibracall 1027 10mm 3V | Formato de moeda, 10 mm de diâmetro e 2,7 mm de altura, com fios.
Eletrônica | Buzzer ativo 5 V (12 mm) | 1 | 2 | Toca o bipe de perigo e o bipe de erro. | buzzer ativo 5V 12mm | Tem que ser ATIVO (toca sozinho quando recebe energia).
Eletrônica | Bateria 14500 de lítio 3,7 V, cerca de 800 mAh, com proteção e terminais para solda | 1 | 1 | Guarda a energia do boné. | bateria 14500 3.7V 800mAh com terminal de solda | Tamanho de uma pilha AA. Precisa vir com placa de proteção (nos anúncios aparece como PCM ou "protegida") e com as lâminas de solda já presas. Desconfie de anúncios de 14500 com 2000 mAh ou mais: não existe.
Eletrônica | Módulo carregador TP4056 com entrada USB-C e proteção | 1 | 2 | Carrega a bateria pelo cabo USB-C e protege contra descarga total. | módulo TP4056 tipo C com proteção | Placa de cerca de 29 x 17 mm, entrada USB-C, com os pontos OUT+ e OUT- (é a versão com proteção).
Eletrônica | Chave gangorra mini KCD11 (2 terminais, liga/desliga) | 1 | 2 | Liga e desliga o boné. | chave gangorra KCD11 15x10mm 2 terminais | Frente de 15 x 10 mm. O case tem um recorte de 13,5 x 9 mm para ela.
Eletrônica | Fusível rearmável 500 mA (PTC) | 1 | 3 | Corta a corrente se o cabo da bateria entrar em curto, e volta a funcionar sozinho. | fusível rearmável PTC 0,5A radial | Modelo de terminais (radial), corrente de 0,5 A.
Eletrônica | Placa ilhada (perfurada) 5 x 7 cm | 1 | 2 | Base onde soldamos a placa, os transistores e os conectores. Vai cortada em 5 x 4 cm. | placa ilhada 5x7 dupla face | Furos com espaçamento de 2,54 mm.
Eletrônica | Barra de pinos fêmea 1 x 8 (2,54 mm) | 2 | 4 | Encaixe da placa ESP32-C3, que fica removível. | barra de pinos fêmea 1x8 2.54mm | Também serve barra fêmea maior, cortada em pedaços de 8.
Componentes pequenos da placa | Transistor 2N2222 | 3 | 5 | Liga os motores e o bipe, que precisam de mais corrente do que a placa fornece. | transistor 2N2222 | Encapsulamento de plástico preto com 3 pernas.
Componentes pequenos da placa | Diodo 1N4148 | 2 | 5 | Protege o circuito do pico de tensão quando um motor desliga. | diodo 1N4148 | Corpo de vidro laranja com uma faixa preta.
Componentes pequenos da placa | Resistor 1 kΩ (1/4 W) | 3 | 10 | Limita a corrente que a placa manda para cada transistor. | resistor 1k 1/4W | Faixas marrom, preto, vermelho.
Componentes pequenos da placa | Resistor 10 kΩ (1/4 W) | 4 | 10 | Reserva para ajustes na placa. | resistor 10k 1/4W | Faixas marrom, preto, laranja.
Componentes pequenos da placa | Resistor 100 kΩ (1/4 W) | 2 | 5 | Vai ser usado para a placa medir a carga da bateria (próximo passo do programa). | resistor 100k 1/4W | Faixas marrom, preto, amarelo.
Componentes pequenos da placa | Resistor de montagem em superfície 3 kΩ (tamanho 0603) | 1 | 5 | Troca o resistor do carregador para ele carregar a 400 mA, a corrente certa para a bateria 14500. | resistor SMD 3K 0603 | Nas lojas aparece como SMD. O tamanho 0603 mede 1,6 x 0,8 mm. Confira no módulo TP4056 se o resistor marcado como R3 (ou 'Rprog') tem esse tamanho.
Componentes pequenos da placa | Capacitor eletrolítico 470 µF 16 V | 2 | 4 | Segura a tensão estável quando os motores ligam (evita a placa reiniciar). | capacitor eletrolítico 470uF 16V | Tem lado certo: a faixa marca o negativo.
Componentes pequenos da placa | Capacitor cerâmico 100 nF | 5 | 10 | Filtra ruído junto aos sensores e motores. | capacitor cerâmico 100nF 104 | Marcado com o número 104.
Componentes pequenos da placa | Capacitor 10 µF (cerâmico ou tântalo) | 2 | 4 | Ajuda a alimentação dos sensores. | capacitor 10uF | Se for eletrolítico, respeite o lado negativo.
Fios, conectores e acabamento dos cabos | Fio de silicone 26 AWG vermelho | 2,2 m | 3 m | Positivo dos sensores, dos motores e da bateria. | fio de silicone 26 AWG vermelho | AWG é a bitola do fio: quanto maior o número, mais fino. O fio de silicone é bem flexível, ideal para o boné.
Fios, conectores e acabamento dos cabos | Fio de silicone 26 AWG preto | 2,2 m | 3 m | Negativo (terra) dos sensores, dos motores e da bateria. | fio de silicone 26 AWG preto | Mesma bitola do vermelho.
Fios, conectores e acabamento dos cabos | Fio de silicone 26 AWG amarelo | 1,1 m | 2 m | Fio de dados (SDA) dos dois sensores. | fio de silicone 26 AWG amarelo
Fios, conectores e acabamento dos cabos | Fio de silicone 26 AWG verde | 1,1 m | 2 m | Fio de relógio (SCL) dos dois sensores. | fio de silicone 26 AWG verde
Fios, conectores e acabamento dos cabos | Fio de silicone 26 AWG azul (ou branco) | 1,1 m | 2 m | Fio que liga e desliga cada sensor (XSHUT), para a placa dar um endereço a cada um. | fio de silicone 26 AWG azul
Fios, conectores e acabamento dos cabos | Fio rígido fino para ligações na placa (pode ser sobra de cabo de rede) | 1 m | 1 m | Pontes de ligação entre os furos da placa ilhada. | fio rígido 24 AWG ou cabo de rede
Fios, conectores e acabamento dos cabos | Par de conectores JST-XH 5 vias, macho e fêmea, com fios já crimpados | 2 pares | 3 pares | Conecta cada sensor à placa sem solda, para desmontar o boné e lavar. | conector JST XH 2.54 5 vias com cabo macho e fêmea | Comprando com os fios já presos não é preciso alicate de crimpar.
Fios, conectores e acabamento dos cabos | Par de conectores JST-XH 2 vias, macho e fêmea, com fios já crimpados | 3 pares | 5 pares | Conecta os dois motores e a bateria. | conector JST XH 2.54 2 vias com cabo macho e fêmea
Fios, conectores e acabamento dos cabos | Kit de tubo termo-retrátil (1,5 a 6 mm) | 1 kit | 1 kit | Isola as emendas e soldas. Encolhe com calor. | kit tubo termo retrátil sortido
Fios, conectores e acabamento dos cabos | Abraçadeira de nylon fina (2,5 x 100 mm) | 10 | 20 | Trava os cabos dentro dos cases, para um puxão não chegar na solda. | abraçadeira nylon 2,5 x 100mm
Parafusos e porcas | Parafuso M2 x 20 mm, cabeça panela | 4 | 6 | Fecha a tampa do case da eletrônica e prende a placa junto. | parafuso M2 x 20 cabeça panela Phillips | M2 é o diâmetro (2 mm) e 20 é o comprimento em milímetros. Cabeça panela é a cabeça arredondada.
Parafusos e porcas | Parafuso M2 x 12 mm, cabeça panela | 4 | 6 | Fecha a tampa do case da bateria. | parafuso M2 x 12 cabeça panela
Parafusos e porcas | Parafuso M2 x 8 mm, cabeça panela | 4 | 6 | Prende os suportes dos sensores na aba. | parafuso M2 x 8 cabeça panela
Parafusos e porcas | Parafuso M2 x 6 mm, cabeça panela | 4 | 6 | Fecha as tampinhas dos suportes dos sensores. | parafuso M2 x 6 cabeça panela
Parafusos e porcas | Parafuso M2 x 8 mm, cabeça chata | 8 | 12 | Prende as placas internas através do tecido do boné. | parafuso M2 x 8 cabeça chata escareada | Cabeça chata (escareada) fica rente à peça, sem saltar.
Parafusos e porcas | Parafuso M2 x 6 mm, cabeça chata | 4 | 6 | Prende o case da eletrônica na base curva. | parafuso M2 x 6 cabeça chata escareada
Parafusos e porcas | Porca M2 | 4 | 8 | Fica presa na plaquinha embaixo da aba, segurando os suportes dos sensores. | porca M2 sextavada
Boné, conforto e costura | Boné de aba curva com regulagem atrás | 1 | 1 | A base do produto. | boné aba curva regulagem strapback | Aba curva, copa estruturada e regulagem atrás. Evite modelos com tela (trucker), porque o tecido precisa segurar os parafusos.
Boné, conforto e costura | Folha de EVA 1 mm (tamanho A4) | 1 | 1 | Forra a bateria dentro do case e faz o calço atrás de cada sensor. | folha EVA 1mm | Preferência pela cor preta.
Boné, conforto e costura | Folha de EVA 2 mm (tamanho A4) | 1 | 1 | Anel em volta de cada motor, para espalhar a pressão. | folha EVA 2mm
Boné, conforto e costura | Folha de EVA 3 mm (tamanho A4) | 1 | 1 | Almofada das placas internas, do lado da cabeça. | folha EVA 3mm
Boné, conforto e costura | Fita de gorgurão ou viés 25 mm, da cor do boné | 0,5 m | 1 m | Vira a canaleta costurada por fora do boné, por onde passam os fios. | fita gorgurão 25mm | A canaleta tem cerca de 40 cm de comprimento.
Boné, conforto e costura | Retalho de tecido macio (algodão ou dry fit), 20 x 20 cm | 1 | 1 | Bolsinhos dos motores, costurados na faixa interna do boné. | retalho tecido dry fit
Boné, conforto e costura | Linha de costura resistente (poliéster) e agulha | 1 | 1 | Costurar a canaleta, os bolsinhos e os berços dos motores. | linha poliéster costura resistente | Cor parecida com a do boné.
Colas e fitas | Cola para tecido | 1 | 1 | Passar em volta dos furos do boné para o tecido não desfiar. | cola para tecido
Colas e fitas | Cola de contato | 1 | 1 | Colar as almofadas de EVA nas placas internas. | cola de contato
Colas e fitas | Bastões de cola quente finos | 3 | 5 | Travar o carregador no case e prender fios. | refil cola quente fina | Precisa da pistola de cola quente.
Colas e fitas | Fita dupla face de espuma fina | 1 rolo | 1 rolo | Entre a base de cada suporte de sensor e a aba, para acompanhar a curva. | fita dupla face espuma 1mm
Ferramentas | Ferro de solda e estanho | 1 | 1 | Soldar os componentes na placa e as emendas dos fios. | ferro de solda 40W e estanho 0,8mm | Só se a equipe ainda não tiver.
Ferramentas | Alicate de corte e alicate desencapador | 1 | 1 | Cortar e descascar os fios. | alicate desencapador de fio
Ferramentas | Chave Phillips de precisão (tamanho 0 ou 1) | 1 | 1 | Apertar os parafusos M2. | chave phillips precisão PH0
Ferramentas | Multímetro | 1 | 1 | Conferir ligações e a tensão da bateria antes de ligar. | multímetro digital
Ferramentas | Paquímetro | 1 | 1 | Medir os componentes antes da impressão final. | paquímetro
Ferramentas | Vazador de 2,5 mm (ou broca de 2,5 mm) | 1 | 1 | Furar o tecido e a aba do boné para os parafusos. | vazador 2,5mm couro
Peças impressas em 3D | Kit de peças impressas (cases, suportes dos sensores, berços dos motores) | 1 kit | 1 kit | Estrutura que prende tudo no boné. | Pedido pronto em modelagem-3d/pedido-de-impressao | Os berços dos motores são em TPU (plástico flexível); o resto em PETG.

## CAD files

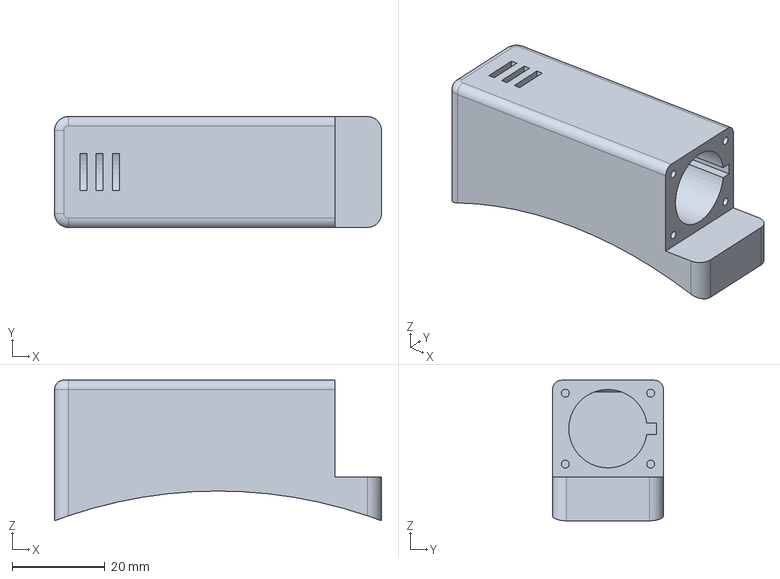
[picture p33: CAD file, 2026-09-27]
modelagem-3d/arquivos-step/B1_case_bateria_corpo.step
70.5 x 23.9 x 30.3 mm

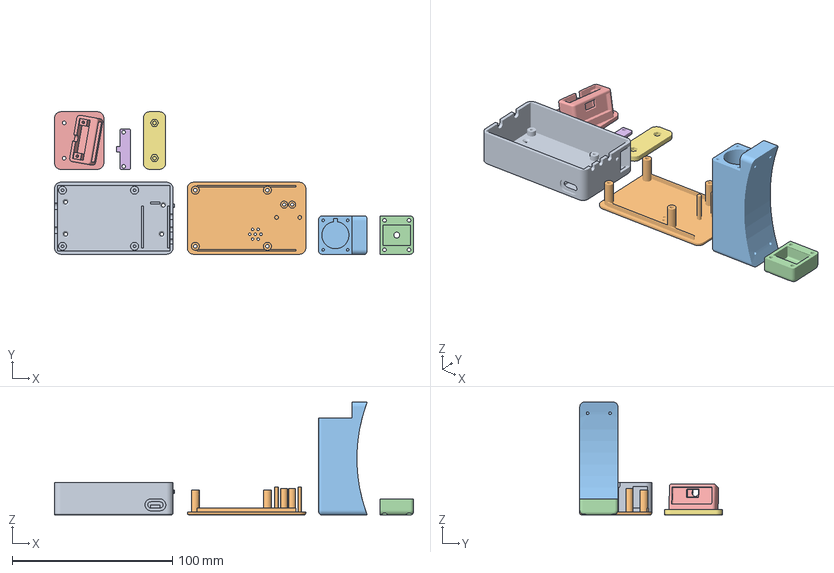
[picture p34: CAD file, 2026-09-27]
modelagem-3d/pedido-de-impressao/lote-1-teste-de-encaixe/lote1_petg.3mf
224.1 x 89.0 x 70.5 mm
A1_case_eletronica_corpo_1
A2_case_eletronica_tampa_1
B1_case_bateria_corpo_1
B2_case_bateria_tampa_1
S1_suporte_sensor_direito_10graus_1
S2_suporte_sensor_tampa_1
S3_suporte_sensor_placa_sob_aba_1

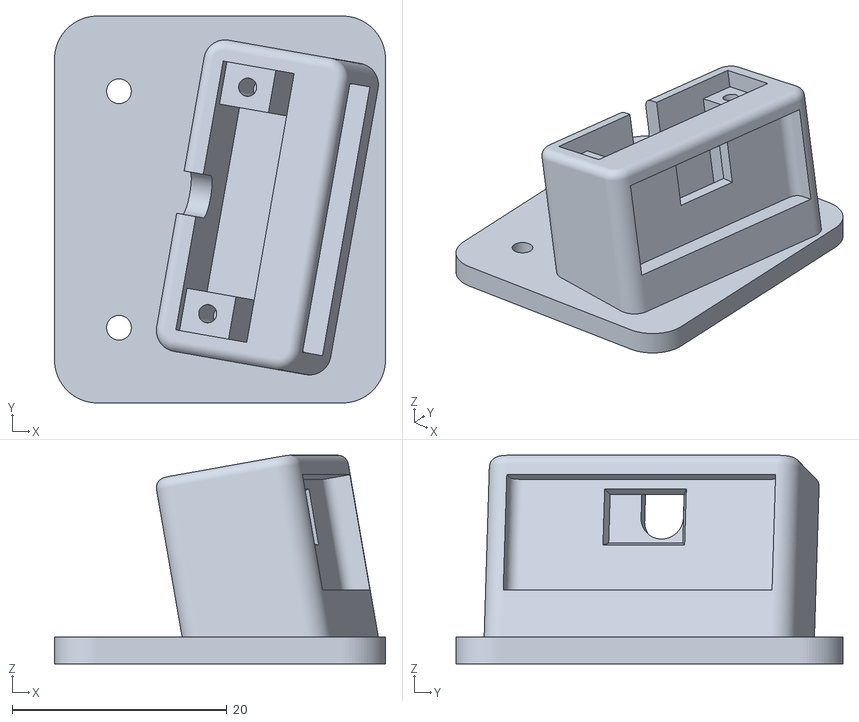
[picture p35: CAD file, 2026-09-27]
modelagem-3d/pedido-de-impressao/lote-1-teste-de-encaixe/stl/S1_suporte_sensor_direito_10graus_x1.stl
30.8 x 36.0 x 19.4

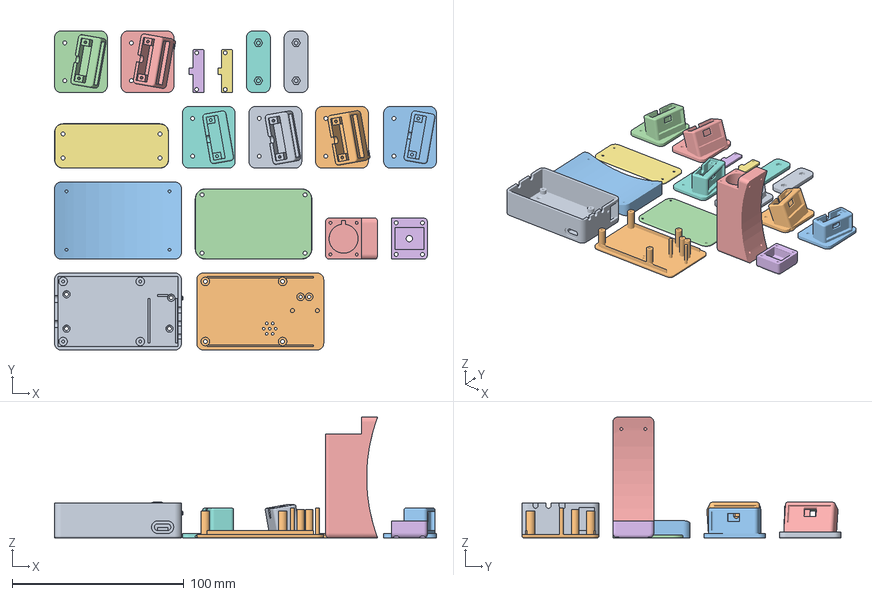
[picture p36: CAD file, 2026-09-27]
modelagem-3d/pedido-de-impressao/lote-2-kit-completo/kit_petg.3mf
222.6 x 186.0 x 70.5 mm
A1_case_eletronica_corpo_1
A2_case_eletronica_tampa_1
A3_case_eletronica_base_curva_1
A4_case_eletronica_placa_interna_1
B1_case_bateria_corpo_1
B2_case_bateria_tampa_1
B3_case_bateria_placa_interna_1
S1_suporte_sensor_esquerdo_00graus_1
S1_suporte_sensor_esquerdo_10graus_1
S1_suporte_sensor_esquerdo_20graus_1
S1_suporte_sensor_direito_00graus_1
S1_suporte_sensor_direito_10graus_1
S1_suporte_sensor_direito_20graus_1
S2_suporte_sensor_tampa_1
S2_suporte_sensor_tampa_2
S3_suporte_sensor_placa_sob_aba_1
S3_suporte_sensor_placa_sob_aba_2

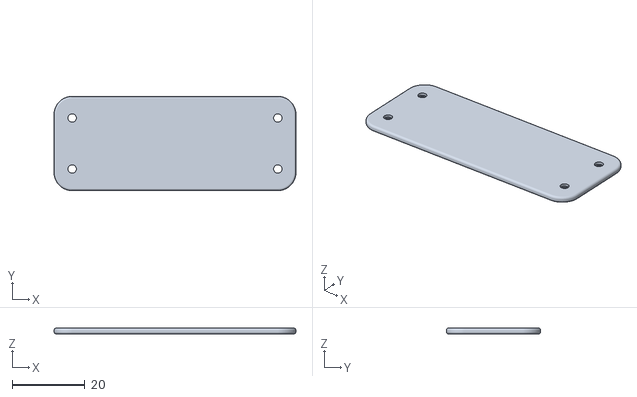
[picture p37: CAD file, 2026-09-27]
modelagem-3d/pedido-de-impressao/lote-2-kit-completo/stl/B3_case_bateria_placa_interna_x1.stl
66.5 x 25.9 x 1.60

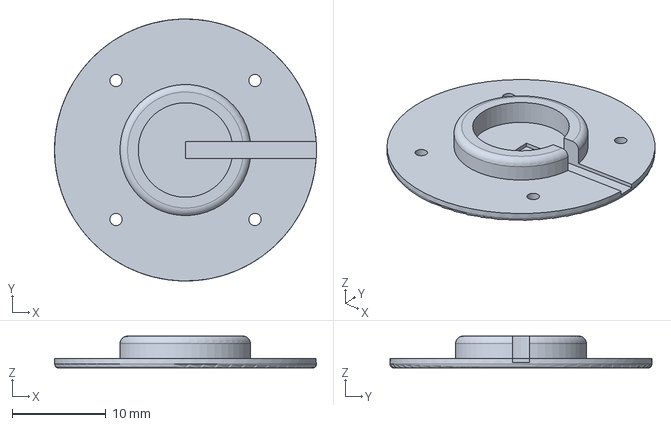
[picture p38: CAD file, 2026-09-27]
modelagem-3d/arquivos-step/M1_berco_motor.step
28.0 x 28.0 x 3.40 mm

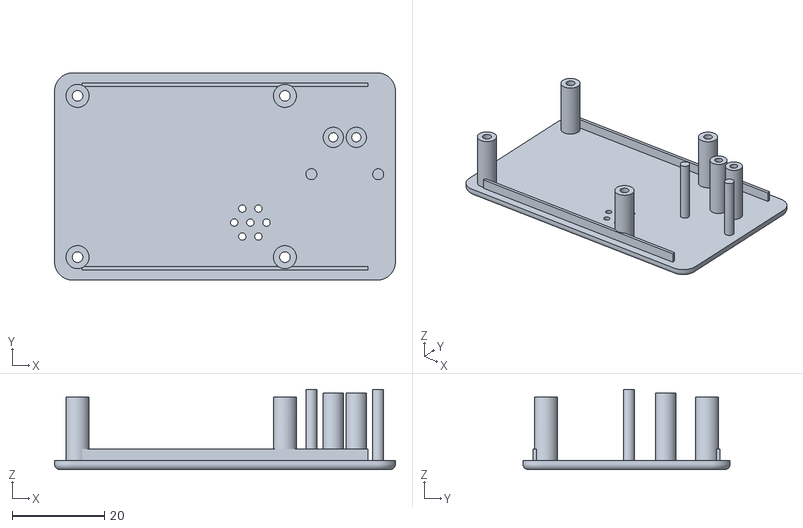
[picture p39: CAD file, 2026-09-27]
modelagem-3d/pedido-de-impressao/lote-1-teste-de-encaixe/stl/A2_case_eletronica_tampa_x1.stl
74.0 x 45.0 x 17.4

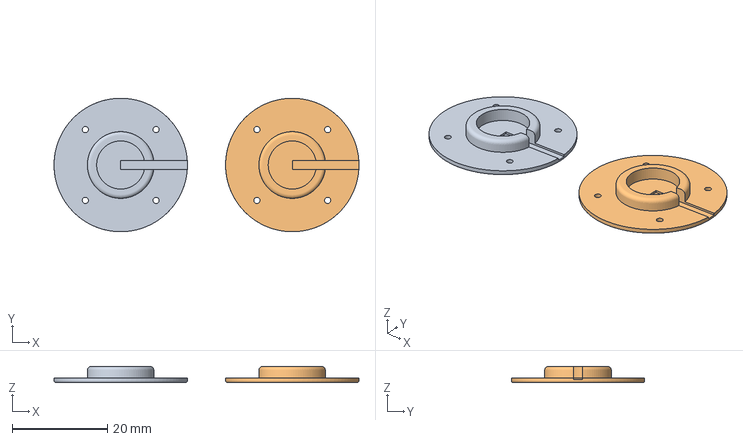
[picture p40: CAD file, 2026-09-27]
modelagem-3d/pedido-de-impressao/lote-2-kit-completo/kit_tpu.3mf
64.0 x 28.0 x 3.40 mm
M1_berco_motor_1
M1_berco_motor_2

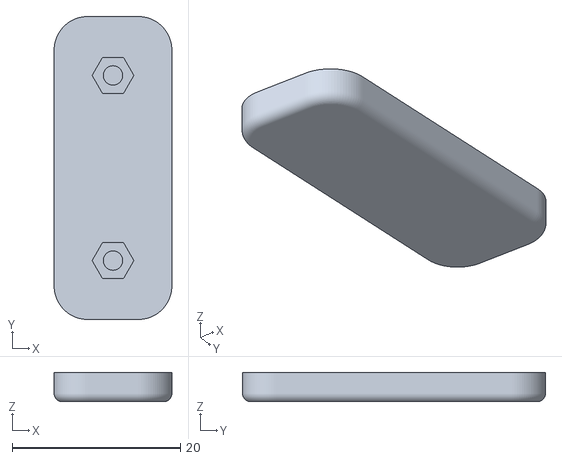
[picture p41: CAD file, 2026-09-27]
modelagem-3d/pedido-de-impressao/lote-2-kit-completo/stl/S3_suporte_sensor_placa_sob_aba_x2.stl
14.0 x 36.0 x 3.50

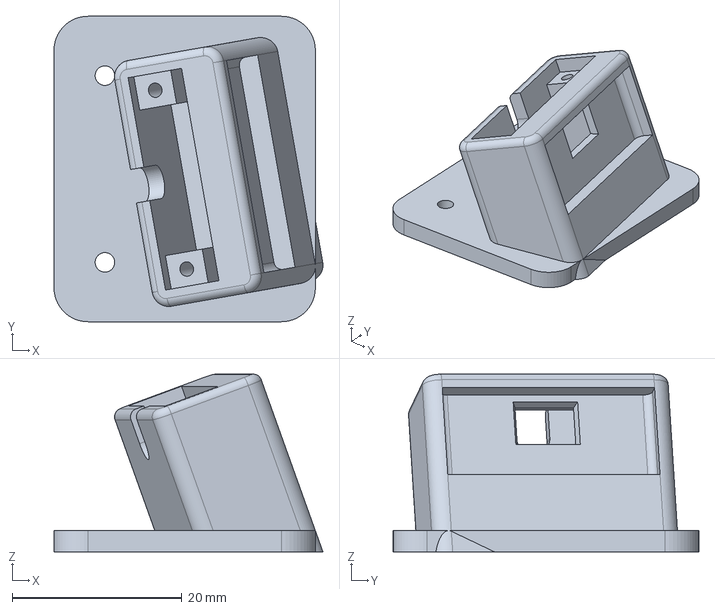
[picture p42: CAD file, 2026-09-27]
modelagem-3d/arquivos-step/S1_suporte_sensor_esquerdo_20graus.step
31.7 x 36.0 x 20.9 mm

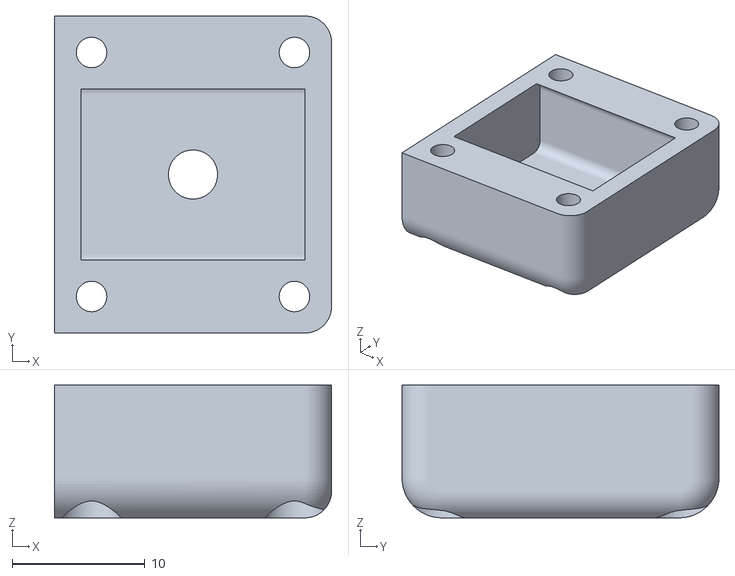
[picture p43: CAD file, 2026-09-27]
modelagem-3d/pedido-de-impressao/lote-1-teste-de-encaixe/stl/B2_case_bateria_tampa_x1.stl
20.9 x 23.9 x 10.00

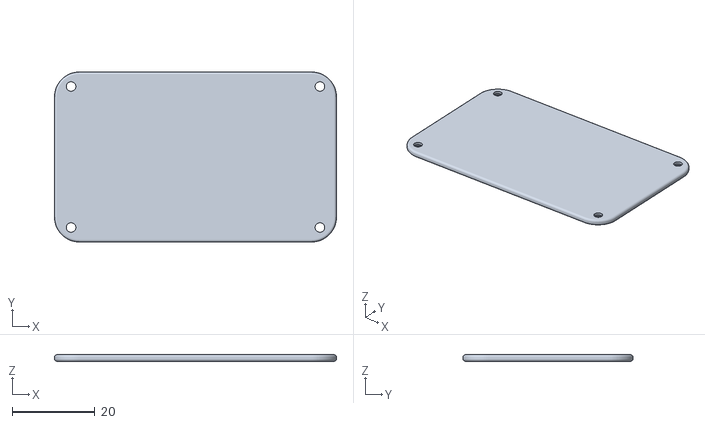
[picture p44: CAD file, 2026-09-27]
modelagem-3d/pedido-de-impressao/lote-2-kit-completo/stl/A4_case_eletronica_placa_interna_x1.stl
68.0 x 41.0 x 1.60

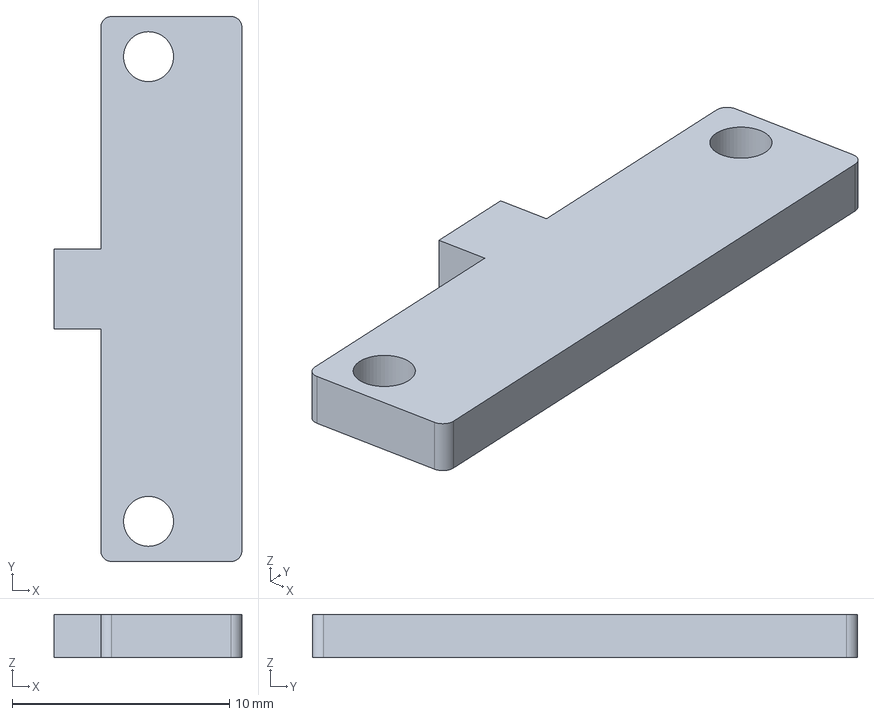
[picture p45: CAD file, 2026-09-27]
modelagem-3d/arquivos-step/S2_suporte_sensor_tampa.step
8.65 x 25.1 x 2.00 mm

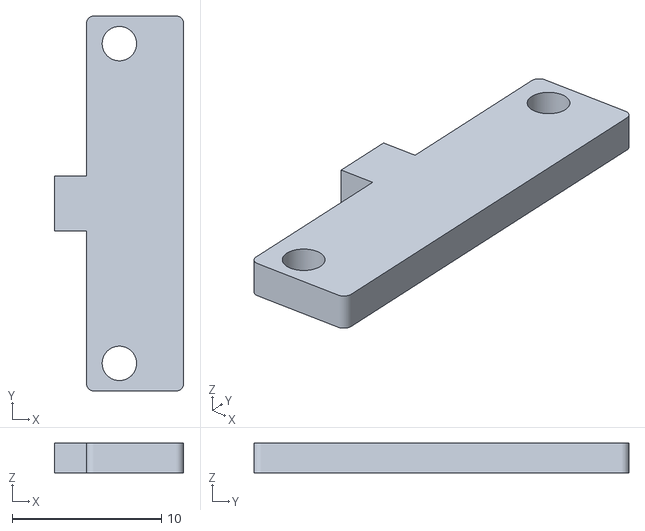
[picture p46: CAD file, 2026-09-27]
modelagem-3d/pedido-de-impressao/lote-1-teste-de-encaixe/stl/S2_suporte_sensor_tampa_x1.stl
8.65 x 25.1 x 2.00

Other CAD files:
modelagem-3d/pedido-de-impressao/lote-1-teste-de-encaixe/lote1_tpu.3mf
modelagem-3d/arquivos-step/A1_case_eletronica_corpo.step
modelagem-3d/pedido-de-impressao/lote-1-teste-de-encaixe/stl/M1_berco_motor_x1.stl
modelagem-3d/arquivos-step/A2_case_eletronica_tampa.step
modelagem-3d/arquivos-step/A3_case_eletronica_base_curva.step
modelagem-3d/arquivos-step/A4_case_eletronica_placa_interna.step
modelagem-3d/arquivos-step/B2_case_bateria_tampa.step
modelagem-3d/arquivos-step/B3_case_bateria_placa_interna.step
modelagem-3d/arquivos-step/S1_suporte_sensor_direito_00graus.step
modelagem-3d/arquivos-step/S1_suporte_sensor_direito_10graus.step
modelagem-3d/arquivos-step/S1_suporte_sensor_direito_20graus.step
modelagem-3d/arquivos-step/S1_suporte_sensor_esquerdo_00graus.step
modelagem-3d/arquivos-step/S1_suporte_sensor_esquerdo_10graus.step
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

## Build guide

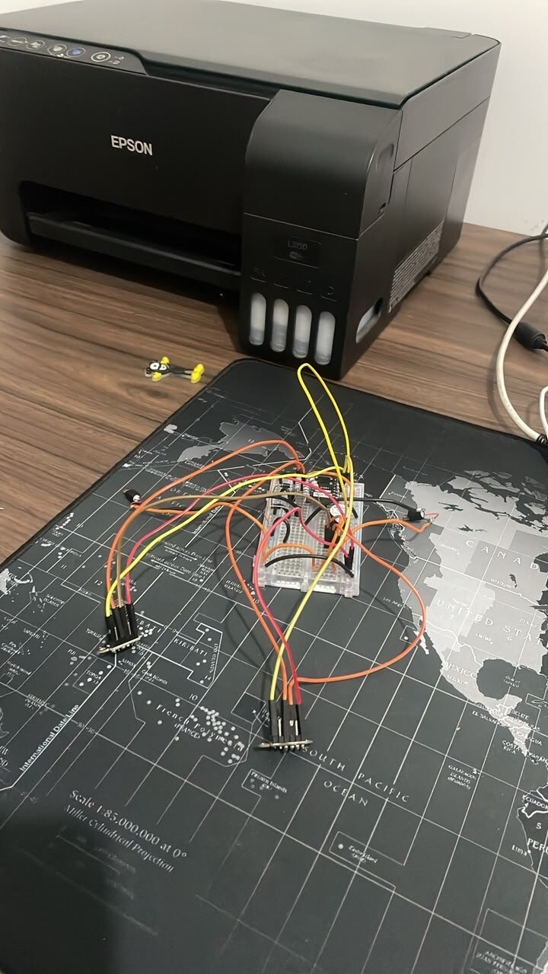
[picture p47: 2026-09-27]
fotos-e-videos/2026-04-montagem-v1-fiacao.jpg

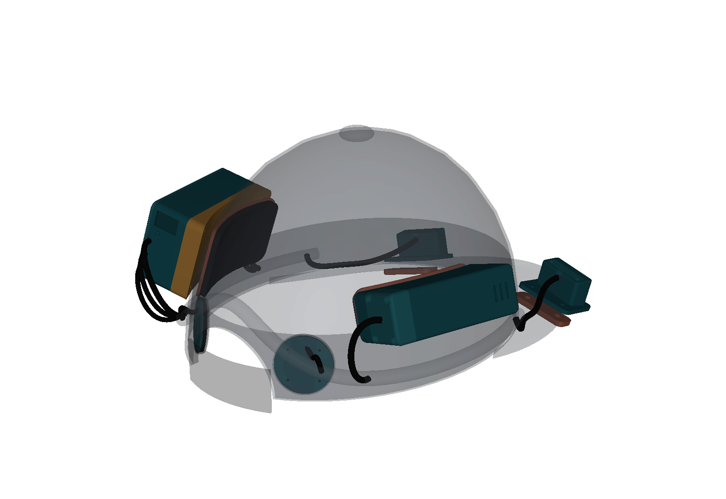
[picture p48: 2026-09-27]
modelagem-3d/imagens/montagem_08_raiox_direita_tras.png

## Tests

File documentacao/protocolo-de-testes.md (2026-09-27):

# Roteiro dos testes de campo

Este é o roteiro que vamos seguir nas sessões de teste com os voluntários da ACACE (de 5 a 10 participantes). Montamos o roteiro assim para sair de cada sessão com números que dê para comparar entre uma versão e outra, e não só com impressões.

## Antes da sessão

- **Percurso.** Escolhemos um percurso em ambiente interno ou na sombra, porque o sensor perde alcance sob sol direto. O percurso é definido antes, é seguro e tem obstáculos "altos" catalogados, na altura do peito e da cabeça. Os obstáculos ficam presos em suportes e não têm pontas.
- **Termos.** O participante assina o Termo de Consentimento Livre e Esclarecido antes de qualquer atividade. A autorização de imagem é um documento separado.
- **Boné conferido.** Bateria carregada, dois bipes de "pronto" ao ligar, lado de cada vibração conferido e 30 minutos de funcionamento sem reiniciar no dia anterior.
- **Código de sessão.** Cada participante recebe um código (por exemplo, S03). Todos os registros usam o código, nunca o nome.

## Como é a sessão, para cada participante

1. **Apresentação (5 a 10 minutos).** A pessoa conhece o boné pelo tato, sente os três níveis de vibração primeiro na mão e depois na cabeça, e ouve o bipe de perigo e o bipe de erro.
2. **Percurso de referência.** Só com a bengala, com alguém da equipe ao lado. Anotamos o tempo e quantas vezes a pessoa esbarra em obstáculos altos.
3. **Percurso com o boné.** Bengala e boné, no mesmo trajeto (ou no trajeto espelhado, para a pessoa não estar só lembrando o caminho). Anotamos as mesmas coisas.
4. **Teste de lado.** Com a pessoa parada, mostramos um obstáculo à esquerda ou à direita, em ordem sorteada, 8 vezes. Ela aponta o lado que sentiu vibrar.
5. **Conforto.** Perguntamos o conforto numa nota de 1 a 5 aos 15 e aos 30 minutos de uso.
6. **Questionário.** Aplicamos a Escala de Usabilidade do Sistema (abaixo) e perguntas abertas sobre peso, pressão e calor.
7. **Conferência da pele.** Depois de tirar o boné, alguém da equipe olha a nuca e as laterais da cabeça, procurando marcas vermelhas nos pontos de contato.

## O que medimos

| O que | Como | Meta |
|---|---|---|
| Esbarrões em obstáculos altos | contagem em cada percurso (referência e com o boné) | cair bem em relação ao percurso de referência |
| Tempo do percurso | cronômetro | não piorar muito |
| Acerto do lado | acertos em 8 tentativas | 7 ou mais |
| Tempo para se acostumar | minutos até a pessoa dizer que está à vontade | só registrar na primeira rodada |
| Escala de Usabilidade do Sistema | questionário de 10 perguntas | acima de 68 (a média de referência da escala) |
| Conforto (peso, pressão, calor) | nota de 1 a 5 aos 15 e aos 30 minutos | 4 ou mais |
| Marcas na pele | conferência da equipe após a sessão | nenhuma |
| Falhas do boné durante a sessão | reinícios, bipes de erro, leituras que somem | nenhuma |

## Escala de Usabilidade do Sistema (a versão que aplicamos)

É um questionário conhecido internacionalmente como SUS (do inglês System Usability Scale). A pessoa responde cada frase de 1 (discordo totalmente) a 5 (concordo totalmente):

1. Eu usaria este boné com frequência.
2. Achei o boné mais complicado do que precisava.
3. Achei o boné fácil de usar.
4. Eu precisaria da ajuda de uma pessoa técnica para conseguir usar.
5. As funções do boné funcionam bem juntas.
6. O boné se comportou de um jeito diferente do esperado em alguns momentos.
7. Imagino que a maioria das pessoas aprenderia a usar rápido.
8. Achei o boné desajeitado ou incômodo de usar.
9. Me senti confiante usando o boné.
10. Precisei aprender muita coisa antes de conseguir usar.

**Como calcular:** nas frases ímpares, subtraia 1 da nota. Nas pares, subtraia a nota de 5. Some tudo e multiplique por 2,5. O resultado vai de 0 a 100.

## Onde registrar

- Uma planilha por sessão, com código, data, versão do programa e do boné e todas as medidas acima.
- Fotos e vídeos só com autorização, na pasta [`fotos-e-videos/`](../fotos-e-videos/), seguindo a regra de nomes de lá.
- O resumo de cada rodada entra no [`HISTORICO.md`](../HISTORICO.md). É assim que o repositório conta a evolução do produto.

<!-- [MÍDIA] depois da primeira rodada na ACACE: adicionar foto do percurso montado e (com autorização) registro da sessão -->

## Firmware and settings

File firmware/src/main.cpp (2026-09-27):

// SPDX-FileCopyrightText: 2026 Edson Gabriel Soares da Fonseca, João Luiz Pereira Filho, Nadson Alex da Silva
// SPDX-License-Identifier: GPL-3.0-only
// ============================================================
// PróVisão · firmware V1.5
// Horizonte Inovação Assistiva · 2026
//
// Evolução de segurança sobre a V1 (preservada em firmware/legado/):
//  1. Teto de PWM nos motores: os vibracall são de 1 a 3 V e o
//     trilho é a tensão da bateria; a V1 mandava 100% do duty.
//  2. Níveis DISCRETOS de vibração com kick-start: a rampa
//     contínua da V1 gerava duty abaixo do limiar de partida do
//     motor, e o usuário não sentia nada na faixa distante.
//  3. Falha de sensor agora é AUDÍVEL e recuperável: a V1
//     travava em silêncio (while(1)), e para um usuário cego um
//     dispositivo mudo é indistinguível de um funcionando.
// ============================================================

#include <Wire.h>
#include "Adafruit_VL53L0X.h"
#include "config.h"

Adafruit_VL53L0X sensorEsq = Adafruit_VL53L0X();
Adafruit_VL53L0X sensorDir = Adafruit_VL53L0X();

// Estado de cada motor para controlar nível e kick-start
struct EstadoMotor {
  uint8_t  pino;
  uint8_t  nivel;       // 0 (desligado) a 3 (forte)
  uint32_t inicioKick;  // millis() em que o nível subiu
};

EstadoMotor motorEsq = { MOTOR_ESQ, 0, 0 };
EstadoMotor motorDir = { MOTOR_DIR, 0, 0 };

uint32_t tempoAnterior = 0;

// ------------------------------------------------------------
// Padrão sonoro de erro: 3 bipes longos.
// Usado quando um sensor não inicializa: o usuário precisa
// SABER que o dispositivo não está protegendo.
// ------------------------------------------------------------
void bipeDeErro() {
  for (int i = 0; i < 3; i++) {
    digitalWrite(PINO_BUZZER, HIGH);
    delay(400);
    digitalWrite(PINO_BUZZER, LOW);
    delay(200);
  }
}

// Dois bipes curtos: sistema pronto.
void bipeDePronto() {
  for (int i = 0; i < 2; i++) {
    digitalWrite(PINO_BUZZER, HIGH);
    delay(80);
    digitalWrite(PINO_BUZZER, LOW);
    delay(80);
  }
}

// ------------------------------------------------------------
// Sequência de inicialização dos dois VL53L0X.
// Eles nascem com o mesmo endereço (0x29), então usamos os
// pinos XSHUT para acordá-los um de cada vez e dar um endereço
// novo ao primeiro. Retorna false se qualquer um falhar.
// ------------------------------------------------------------
bool iniciarSensores() {
  digitalWrite(XSHUT_ESQ, LOW);
  digitalWrite(XSHUT_DIR, LOW);
  delay(10);

  digitalWrite(XSHUT_ESQ, HIGH);
  delay(10);
  if (!sensorEsq.begin(ADDR_SENSOR_ESQ)) {
    Serial.println(F("ERRO: sensor esquerdo nao respondeu."));
    return false;
  }

  digitalWrite(XSHUT_DIR, HIGH);
  delay(10);
  if (!sensorDir.begin(ADDR_SENSOR_DIR)) {
    Serial.println(F("ERRO: sensor direito nao respondeu."));
    return false;
  }
  return true;
}

// Converte distância (mm) em nível de vibração (0 a 3).
uint8_t nivelPorDistancia(int dist_mm) {
  if (dist_mm <= 0)            return 0;   // leitura inválida
  if (dist_mm <= DIST_NIVEL_3) return 3;
  if (dist_mm <= DIST_NIVEL_2) return 2;
  if (dist_mm <= DIST_NIVEL_1) return 1;
  return 0;
}

// ------------------------------------------------------------
// Aplica o nível ao motor com kick-start: ao ENTRAR num nível
// mais alto, o motor recebe um pulso curto em duty máximo para
// vencer a inércia e então assenta no duty do nível.
// ------------------------------------------------------------
void atualizarMotor(EstadoMotor &m, uint8_t novoNivel, uint32_t agora) {
  if (novoNivel > m.nivel) {
    m.inicioKick = agora;  // subiu de nível: dispara o empurrão
  }
  m.nivel = novoNivel;

  uint8_t duty;
  if (m.nivel > 0 && (agora - m.inicioKick) < KICK_MS) {
    duty = DUTY_KICK;
  } else {
    duty = DUTY_NIVEL[m.nivel];
  }
  analogWrite(m.pino, duty);
}

void setup() {
  Serial.begin(115200);

  pinMode(MOTOR_ESQ, OUTPUT);
  pinMode(MOTOR_DIR, OUTPUT);
  pinMode(PINO_BUZZER, OUTPUT);
  pinMode(XSHUT_ESQ, OUTPUT);
  pinMode(XSHUT_DIR, OUTPUT);

  analogWrite(MOTOR_ESQ, 0);
  analogWrite(MOTOR_DIR, 0);
  digitalWrite(PINO_BUZZER, LOW);

  Wire.begin(PINO_SDA, PINO_SCL);

  // Diferente da V1: se um sensor falhar, o dispositivo AVISA
  // com bipes e tenta de novo, nunca trava em silêncio.
  while (!iniciarSensores()) {
    bipeDeErro();
    delay(RETRY_SENSOR_MS);
  }

  Serial.println(F("PróVisão V1.5 iniciada."));
  bipeDePronto();
}

void loop() {
  uint32_t agora = millis();
  if (agora - tempoAnterior < INTERVALO_LEITURA_MS) return;
  tempoAnterior = agora;

  VL53L0X_RangingMeasurementData_t medidaEsq;
  VL53L0X_RangingMeasurementData_t medidaDir;
  sensorEsq.rangingTest(&medidaEsq, false);
  sensorDir.rangingTest(&medidaDir, false);

  // RangeStatus 4 = fora de alcance; tratamos como "longe".
  int distEsq = (medidaEsq.RangeStatus != 4) ? medidaEsq.RangeMilliMeter : 8000;
  int distDir = (medidaDir.RangeStatus != 4) ? medidaDir.RangeMilliMeter : 8000;

  atualizarMotor(motorEsq, nivelPorDistancia(distEsq), agora);
  atualizarMotor(motorDir, nivelPorDistancia(distDir), agora);

  // Proximidade crítica em qualquer lado dispara o buzzer.
  bool critico = (distEsq > 0 && distEsq <= DIST_CRITICA) ||
                 (distDir > 0 && distDir <= DIST_CRITICA);
  digitalWrite(PINO_BUZZER, critico ? HIGH : LOW);

  // TODO (V2): interface ITelemetry para registrar distâncias,
  // níveis e tensão da bateria para análise pós-teste.
}

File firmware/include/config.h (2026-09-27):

// SPDX-FileCopyrightText: 2026 Edson Gabriel Soares da Fonseca, João Luiz Pereira Filho, Nadson Alex da Silva
// SPDX-License-Identifier: GPL-3.0-only
// ============================================================
// PróVisão · configuração central do firmware
// Tudo que é ajuste de calibração fica aqui. A lógica não
// precisa ser tocada para mudar pino, distância ou intensidade.
// ============================================================
#pragma once

#include <Arduino.h>

// ---------- Pinos (ESP32-C3 Super Mini) ----------
#define MOTOR_ESQ    0   // vibracall esquerdo (via transistor)
#define MOTOR_DIR    1   // vibracall direito  (via transistor)
#define PINO_BUZZER  3   // buzzer ativo       (via transistor)
#define PINO_SDA     4   // I2C dados
#define PINO_SCL     5   // I2C clock
#define XSHUT_ESQ    6   // desligamento do sensor esquerdo
#define XSHUT_DIR    7   // desligamento do sensor direito

// ---------- Endereços I2C dos sensores ----------
#define ADDR_SENSOR_ESQ 0x30  // remapeado no boot
#define ADDR_SENSOR_DIR 0x29  // endereço padrão do VL53L0X

// ---------- Distâncias (milímetros) ----------
const int DIST_NIVEL_1   = 1500; // começa a vibrar (nível fraco)
const int DIST_NIVEL_2   = 1000; // vibração média
const int DIST_NIVEL_3   = 500;  // vibração forte
const int DIST_CRITICA   = 300;  // buzzer

// ---------- Vibração ----------
// Os motores são de 1–3 V e o trilho é a tensão da bateria
// (3,3–4,2 V), então limitamos o PWM para não sobrecarregá-los.
const uint8_t DUTY_NIVEL[4] = { 0, 90, 140, 180 }; // por nível (0 a 3)
const uint8_t DUTY_KICK     = 255;  // "empurrão" para vencer a inércia
const uint16_t KICK_MS      = 30;   // duração do empurrão

// ---------- Tempos ----------
const uint32_t INTERVALO_LEITURA_MS = 50;
const uint32_t RETRY_SENSOR_MS      = 5000; // nova tentativa após falha

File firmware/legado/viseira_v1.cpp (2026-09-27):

// SPDX-FileCopyrightText: 2026 Edson Gabriel Soares da Fonseca, João Luiz Pereira Filho, Nadson Alex da Silva
// SPDX-License-Identifier: MIT
// ============================================================
// PróVisão · firmware V1 (2026.1) · PRESERVADO COMO HISTÓRICO
// Esta é a versão apresentada na disciplina e demonstrada à
// ACACE, exatamente como rodou na protoboard. Não usar em
// builds novos: a V1.5 (firmware/src/) corrige a sobretensão
// dos motores, o limiar de partida da vibração e a falha
// silenciosa de sensor. Mantemos o arquivo pelo registro
// cronológico do projeto.
// ============================================================

#include <Wire.h>
#include "Adafruit_VL53L0X.h"

// ==========================================
// MAPA DE PINOS DEFINITIVO PARA PROTOBOARD
// (Baseado na serigrafia real do ESP32-C3)
// ==========================================
#define MOTOR_ESQ 0     // Transistor Esq (Furo D8)
#define MOTOR_DIR 1     // Transistor Dir (Furo D7)
#define PINO_BUZZER 3   // Transistor Buzzer (Furo D5)

#define PINO_SDA 4      // I2C Dados (Furos B4/C4)
#define PINO_SCL 5      // I2C Clock (Furo J1)
#define XSHUT_ESQ 6     // Desligamento Esq (Furo J2)
#define XSHUT_DIR 7     // Desligamento Dir (Furo J3)

// ==========================================
// CONFIGURAÇÕES DE DISTÂNCIA (em milímetros)
// ==========================================
const int DISTANCIA_MAXIMA = 1500; // 150 cm - Começa a vibrar
const int DISTANCIA_MINIMA = 200;  // 20 cm - Vibração máxima
const int DISTANCIA_CRITICA = 300; // 30 cm - Ativa o Buzzer

Adafruit_VL53L0X sensorEsq = Adafruit_VL53L0X();
Adafruit_VL53L0X sensorDir = Adafruit_VL53L0X();

unsigned long tempoAnterior = 0;
const long intervaloLeitura = 50;

void setup() {
  Serial.begin(115200);

  pinMode(MOTOR_ESQ, OUTPUT);
  pinMode(MOTOR_DIR, OUTPUT);
  pinMode(PINO_BUZZER, OUTPUT);

  analogWrite(MOTOR_ESQ, 0);
  analogWrite(MOTOR_DIR, 0);
  digitalWrite(PINO_BUZZER, LOW);

  pinMode(XSHUT_ESQ, OUTPUT);
  pinMode(XSHUT_DIR, OUTPUT);

  digitalWrite(XSHUT_ESQ, LOW);
  digitalWrite(XSHUT_DIR, LOW);
  delay(10);

  Wire.begin(PINO_SDA, PINO_SCL);

  digitalWrite(XSHUT_ESQ, HIGH);
  delay(10);
  if (!sensorEsq.begin(0x30)) {
    Serial.println(F("ERRO: Falha no Sensor Esquerdo!"));
    while(1);
  }

  digitalWrite(XSHUT_DIR, HIGH);
  delay(10);
  if (!sensorDir.begin(0x29)) {
    Serial.println(F("ERRO: Falha no Sensor Direito!"));
    while(1);
  }

  Serial.println(F("Sistema Inicializado. Iniciando medições..."));
}

void loop() {
  unsigned long tempoAtual = millis();

  if (tempoAtual - tempoAnterior >= intervaloLeitura) {
    tempoAnterior = tempoAtual;

    VL53L0X_RangingMeasurementData_t medidaEsq;
    VL53L0X_RangingMeasurementData_t medidaDir;

    sensorEsq.rangingTest(&medidaEsq, false);
    sensorDir.rangingTest(&medidaDir, false);

    int distEsq = medidaEsq.RangeStatus != 4 ? medidaEsq.RangeMilliMeter : 8000;
    int distDir = medidaDir.RangeStatus != 4 ? medidaDir.RangeMilliMeter : 8000;

    int forcaMotorEsq = 0;
    int forcaMotorDir = 0;

    if (distEsq <= DISTANCIA_MAXIMA && distEsq > 0) {
      if (distEsq <= DISTANCIA_MINIMA) {
        forcaMotorEsq = 255;
      } else {
        forcaMotorEsq = map(distEsq, DISTANCIA_MAXIMA, DISTANCIA_MINIMA, 50, 255);
      }
    }

    if (distDir <= DISTANCIA_MAXIMA && distDir > 0) {
      if (distDir <= DISTANCIA_MINIMA) {
        forcaMotorDir = 255;
      } else {
        forcaMotorDir = map(distDir, DISTANCIA_MAXIMA, DISTANCIA_MINIMA, 50, 255);
      }
    }

    analogWrite(MOTOR_ESQ, forcaMotorEsq);
    analogWrite(MOTOR_DIR, forcaMotorDir);

    if ((distEsq <= DISTANCIA_CRITICA && distEsq > 0) || (distDir <= DISTANCIA_CRITICA && distDir > 0)) {
      digitalWrite(PINO_BUZZER, HIGH);
    } else {
      digitalWrite(PINO_BUZZER, LOW);
    }
  }
}

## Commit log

2026-09-27 Revisa os comentários do firmware e documenta a pasta
    Trocamos os travessões dos comentários por dois-pontos e vírgulas,
    seguindo o padrão de escrita que definimos para o repositório, e
    reescrevemos em português claro o comentário da verificação automática.
    Criamos o firmware/README.md para explicar como compilar, gravar e
    calibrar o programa da placa sem pressupor experiência com o PlatformIO.
2026-09-27 Move a eletrônica para eletronica/ com o esquema da V1.5
    Substituímos a pasta hardware/ por eletronica/, com nome em português.
    O esquema elétrico passou a descrever as ligações da V1.5 pino por pino,
    e a lista de materiais virou lista-de-materiais.csv, com a função de
    cada item e como procurá-lo na loja.
    Mantivemos a CERN-OHL-P 2.0 em LICENCA-HARDWARE.md, agora cobrindo
    também as peças 3D.
    [BOM.csv, lista-de-materiais.csv]
2026-09-27 Adiciona a modelagem 3D das peças da V1.5
    Desenhamos em código todas as peças impressas do boné: case da
    eletrônica, case da bateria, suportes dos sensores em três inclinações e
    berços dos motores. Concentramos as medidas em pecas/medidas.py para que
    uma medida real diferente seja corrigida num lugar só, e criamos o
    verificar_encaixes.py para conferir os encaixes antes de qualquer
    impressão.
    A pasta traz também os arquivos STEP e STL, as imagens das peças, o
    boné montado em GLB e o pacote do pedido de impressão em dois lotes.
    Ela substitui a pasta enclosure/, que ainda não tinha peças.
    [A1_case_eletronica_corpo.step, A1_case_eletronica_corpo.stl, A1_case_eletronica_corpo_x1.stl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]
2026-09-27 Reorganiza a documentação em pastas em português
    Renomeamos docs/ para documentacao/, media/ para fotos-e-videos/ e o
    CHANGELOG.md para HISTORICO.md, para o repositório ficar mais fácil de
    entender. Mantivemos em inglês só README.md, LICENSE e CONTRIBUTING.md,
    que o GitHub reconhece e destaca.
    Reescrevemos o README, o guia de contribuição e os documentos de
    funcionamento, segurança e roteiro de testes numa linguagem mais
    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
2026-09-27 Organiza o acervo de fotos e vídeos dos principais eventos
    Reunimos em fotos-e-videos/ os registros da simulação e do primeiro
    teste do código, da montagem do protótipo V1, da primeira reunião com a
    ACACE, da apresentação na disciplina e da feira de profissões de 17 de
    setembro de 2026. Reduzimos as fotos para até 1 MB e transformamos os
    vídeos em GIFs curtos, de até 3 MB, para o repositório continuar leve.
    Os originais ficam em fotos-e-videos/originais/, fora do Git.
    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
2026-09-27 Adota licenças abertas e recíprocas
    Queremos que ninguém se aproprie do trabalho técnico da PróVisão sem
    devolver as melhorias. As licenças que escolhemos em julho (MIT,
    CERN-OHL-P 2.0 e CC BY-SA 4.0) permitiam copiar, modificar e vender sem
    abrir nada, então trocamos:
    - programa da placa: GPL-3.0-only, com o texto em firmware/LICENSE;
    - eletrônica e peças 3D: CERN-OHL-S 2.0;
    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
2026-09-27 Formaliza a ficha do pedido de impressão 3D
    A ficha vai para o serviço de impressão, então reescrevemos o texto em
    tom técnico e impessoal, com seções numeradas, especificações no
    imperativo e critérios de aceitação na entrega. Ajustamos as colunas da
    tabela para os nomes dos arquivos não quebrarem no meio.
    Acrescentamos ao gerar_pedido_impressao.py a opção --so-ficha, que refaz
    só o PDF sem regerar os arquivos 3MF e STL.

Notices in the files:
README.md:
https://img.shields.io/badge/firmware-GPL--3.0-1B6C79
